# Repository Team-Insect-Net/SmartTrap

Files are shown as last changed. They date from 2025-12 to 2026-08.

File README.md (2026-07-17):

# SmartTrap v2.0

**Low-Power IoT Moth Trap Counter for Fall Armyworm Monitoring**

An automated monitoring system that detects, counts, and photographs moth entries into pheromone bucket traps. Designed for sustainable Fall Armyworm (FAW) management in agricultural settings.





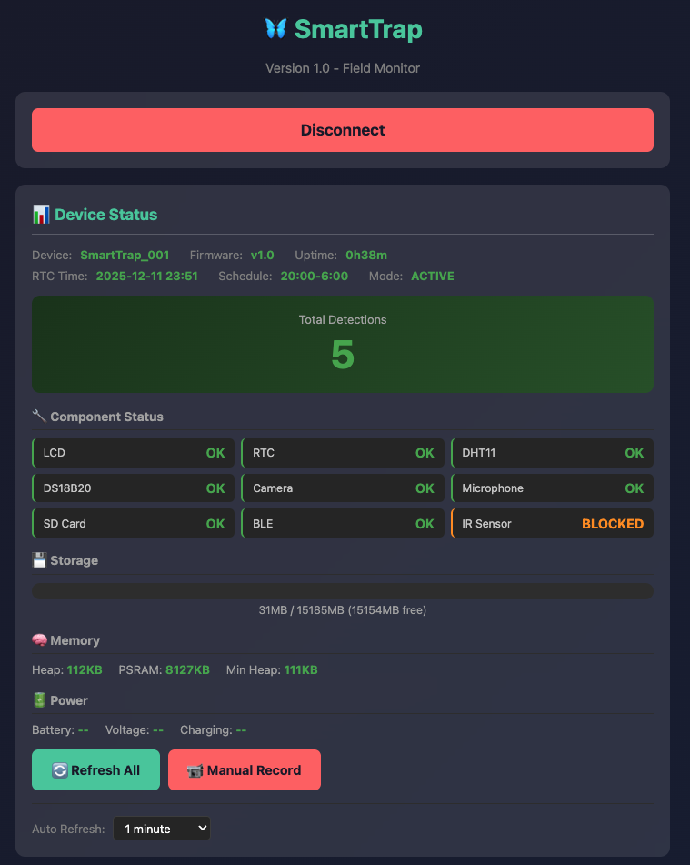
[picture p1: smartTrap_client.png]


---

## Overview

SmartTrap is a low-cost IoT device that automates the monitoring of Fall Armyworm moth populations. It uses a multi-beam infrared array to count moths entering pheromone traps, captures a JPEG image burst on each detection, and provides all control and data access over Bluetooth Low Energy (BLE) through the **SmartTrap Android app**.

> **v2.0 is a major redesign — BLE-native, button-less, and screen-less.** The phone app replaces the physical button and 16×2 LCD. The environmental sensors (air temperature/humidity, soil temperature, soil moisture) and AVI/WAV recording from v1.x have been removed; detections are now recorded as JPEG bursts. See the [changelog](#whats-new-in-v20).

### 📱 Android App

The SmartTrap Android app is the primary interface for the trap (status, diagnostics, time-setting, file browsing/download, count reset, and WiFi/USB control).

**Download the APK:** <https://drive.google.com/file/d/1rnNRD0PhtQwLzY0d07APNC46B7DXw_hL/view?usp=sharing>

Install by enabling "Install unknown apps" for your browser or file manager, open the downloaded APK, then grant Bluetooth (and Location, if prompted) permissions. Pair with the trap using passkey **`123456`**.

### Key Applications
- Fall Armyworm population monitoring
- Agricultural research and pest management
- Integrated Pest Management (IPM) decision support
- Scalable deployment across multiple field sites

### What's new in v2.0
- **[REMOVED]** Physical button and 16×2 LCD — all interaction is over BLE via the phone app
- **[REMOVED]** Environmental sensors (DHT11, DS18B20, soil moisture) and environmental logging
- **[CHANGED]** Detection recording is now a 10-frame JPEG burst (was AVI video + WAV audio)
- **[CHANGED]** IR detection upgraded to a 4-beam array driven from two pins
- **[NEW]** BLE re-added on the low-RAM NimBLE stack so it can coexist with the camera
- **[NEW]** On-demand WiFi SoftAP + HTTP server for fast bulk image download
- **[NEW]** Set the RTC from the phone app (`SETTIME`) — no re-flash or SetRTC sketch needed for routine time-setting

---

## Features

### Core Functionality
- **4-Beam IR Detection** - Multi-beam beam-break array with debounce filtering
- **JPEG Burst Capture** - 10-frame image burst (1s apart) on each detection
- **Scheduled Daily Photo** - Optional timed reference photo (default 08:00)
- **CSV Logging** - Detection events, beam-health, and daily-photo logs
- **SD Card Storage** - Local data storage with organized folder structure

### Data Management
- **Phone App over BLE** - Status, diagnostics, file browsing/download, and count reset from the Android app
- **On-Demand WiFi Download** - `WIFI:ON` raises a SoftAP + HTTP server for fast bulk image transfer
- **USB Mass Storage** - Mount the SD card as a USB drive via the `USB` BLE command
- **Auto Count Recovery** - Detection count derived from SD card data; survives reboots, resets on data deletion
- **Bonded BLE Security** - Passkey pairing with an encrypted link (legacy plaintext fallback for the old web client)

### Power Management
- **Scheduled Sleep Mode** - Optional configurable active hours (default off; 8 PM - 6 AM when enabled)
- **Deep Sleep** - Ultra-low power consumption during inactive periods
- **RTC-Timer Wake** - Wake from deep sleep on the DS3231 timer
- **Battery Support** - 3.7V LiPo battery or Power Bank (20,000 mAh) with USB charging

### Phone App (BLE)
- **Real-time Status** - Device info, uptime, schedule, detection count (`STATUS`)
- **Component Health** - Camera, mic, SD, RTC, BLE, and IR status (`DIAG`)
- **Memory Info** - Heap and PSRAM monitoring
- **Live Pushes** - `EVENT` on each detection, `BEAM:BLOCKED`/`BEAM:RESTORED` on beam-health changes
- **Time Sync** - Set the RTC from the app (`SETTIME`)

---

## Hardware Requirements

### Main Components

| Component | Model | Qty | Purpose |
|---|---|-----|---|
| Microcontroller | XIAO ESP32S3 Sense | 1 | Processing, camera, microphone, SD card |
| Real-Time Clock | DS3231 | 1 | Accurate timestamps |
| IR Emitter | 940nm LED | 4 | Beam-break transmitters |
| IR Receiver | 38kHz module | 4 | Beam-break receivers |
| Android phone | Runs the SmartTrap app (BLE 4.2+) | 1 | Device interface |

*Removed in v2.0: 16×2 LCD, DHT11, DS18B20, soil-moisture sensor, and push button.*



### Resistors Required (4 total)

| Value | Color Code | Purpose | Connection |
|---|---|---|---|
| 100Ω | Brown-Black-Brown | IR LED current limit (one per LED) | Drive pin → IR LED → GND |

*The IR receivers use the ESP32's internal pull-up (`INPUT_PULLUP`) — no external pull-up/pull-down resistors are needed.*

### Pin Configuration

```
D0 (GPIO1)  → IR LED pair #2 (LEDs #3+#4) via 100Ω each, 38kHz PWM
D1 (GPIO2)  → FREE (was DS18B20)
D2 (GPIO3)  → FREE (was DHT11)
D3 (GPIO4)  → FREE (was Button)
D4 (GPIO5)  → I2C SDA (RTC only)
D5 (GPIO6)  → I2C SCL (RTC only)
D6 (GPIO43) → IR LED pair #1 (LEDs #1+#2) via 100Ω each, 38kHz PWM
D7 (GPIO44) → IR Receivers ×4 (parallel, internal pull-up; blocked = LOW)
D8-D10      → RESERVED (SD Card - do not use)
```

---

## Software Requirements

### Arduino IDE Setup

1. **Install Arduino IDE 2.0+** from [arduino.cc](https://www.arduino.cc/en/software)

2. **Add ESP32 Board Package**
   - Go to `File → Preferences`
   - Add to "Additional Boards Manager URLs":
     ```
     https://raw.githubusercontent.com/espressif/arduino-esp32/gh-pages/package_esp32_index.json
     ```
   - Go to `Tools → Board → Boards Manager`
   - Search "esp32" and install (version 2.0.8 or higher)

3. **Select Board Settings**
   - Board: `ESP32S3 Dev Module`
   - USB CDC On Boot: `Enabled` ⚠️ Required for Serial output
   - PSRAM: `OPI PSRAM`
   - Port: Select your device port

### Required Libraries

Install via `Sketch → Include Library → Manage Libraries`:

- `NimBLE-Arduino` by h2zero (v1.4.x) - BLE stack (do **not** also enable Bluedroid)
- `RTClib` - DS3231 real-time clock

*The v1.x sensor/LCD libraries (LiquidCrystal I2C, DHT sensor library, OneWire, DallasTemperature) are no longer needed.*

---

## Installation

1. **Clone the repository**
   ```bash
   git clone https://github.com/Team-Insect-Net/SmartTrap.git
   cd SmartTrap
   ```

2. **Open the firmware**
   - Open `SmartTrap.ino` in Arduino IDE

3. **Configure settings** (optional)
   ```cpp
   #define DEVICE_NAME         "SmartTrap_001"    // Unique device ID (BLE + WiFi)
   #define BLE_PASSKEY         123456             // 6-digit BLE pairing passkey
   #define AUTH_PASSWORD       "smart2025"        // Legacy plaintext fallback
   #define WIFI_AP_PASSWORD    "trap12345"        // On-demand WiFi image server
   #define JPEG_BURST_COUNT    10                 // Frames captured per detection
   #define DAILY_PHOTO_HOUR    8                  // Scheduled daily photo (−1 = off)
   ```

4. **Upload to device**
   - Connect XIAO ESP32S3 Sense via USB-C
   - Select correct port in Arduino IDE
   - Click Upload

5. **Verify installation**
   - Open Serial Monitor (115200 baud)
   - Check all components show "OK"

---

## Usage

The device runs automatically on power-up — there is no button or LCD. Everything else is done from the **SmartTrap Android app** over BLE. Pair once with passkey **`123456`**; the bonded, encrypted link then authorizes protected commands.

### Connecting

1. Install and open the Android app (see [Android App](#-android-app) above)
2. Scan and connect to your trap (default BLE name `SmartTrap_001`)
3. Enter the pairing passkey `123456` when prompted

### BLE Commands

| Command | Access | Description |
|---|---|---|
| `STATUS` | open | Device info, uptime, schedule, detection count |
| `DIAG` | open | Camera/mic/SD/RTC/BLE/IR status + memory |
| `DETECTIONS` | open | Current detection count |
| `PING` | open | Liveness check (`PONG`) |
| `LIST` / `CD:` / `GET:` | protected | Browse and download SD card files |
| `DELETE:` / `RESET` | protected | Delete files / wipe data and zero the count |
| `SETTIME:YYYY-MM-DD HH:MM:SS` | protected | Set the RTC from the phone |
| `WIFI:ON` / `WIFI:OFF` | protected | Raise / tear down the WiFi image server |
| `USB` | protected | Mount the SD card as a USB Mass Storage drive |

Live pushes: `EVENT:det=…` on each detection, `BEAM:BLOCKED`/`BEAM:RESTORED` on beam-health changes. Full spec: **[BLE Protocol](docs/SmartTrap_v2.0_BLE_Protocol.md)**.

### Getting Data Off the Trap

- **Photos (fast):** send `WIFI:ON` → join the trap's WiFi (`SmartTrap_001` / `trap12345`) → download JPEGs over HTTP → `WIFI:OFF`
- **Logs:** browse with `LIST`/`CD` and download with `GET` over BLE
- **Bulk:** send `USB` to mount the SD card over USB-C, or pull the microSD card

### Resetting Detection Count

The moth count is derived from `detections.csv`. To reset: send **`RESET`** over BLE, or delete `/events/` and `/logs/` in USB drive mode, then reboot — count starts at 0.

### Legacy Web Client (optional)

The old `SmartTrap_v1.0_Client.html` still connects via the plaintext `AUTH:smart2025` fallback (Chrome + Web Bluetooth, served over localhost), but the Android app is the recommended interface.

### Data Files

```
/events/
  └── YYYYMMDD/                     # Daily detection folders
      └── img_<timestamp>_f<n>.jpg  # 10-frame JPEG burst per detection

/daily/
  └── YYYYMMDD_HH.jpg               # Scheduled daily photo(s)

/logs/
  ├── detections.csv               # Detection events
  ├── beam_health.csv              # IR beam block/restore log
  └── daily_photos.csv             # Scheduled-photo log
```

---

## Data Format

### detections.csv
```csv
timestamp,detection_num,event_dir,burst_timestamp,frames,audio_file
2026-07-17 21:45:32,1,/events/20260717,214532,10,
```

### beam_health.csv
```csv
timestamp,event,ir_receiver_state
2026-07-17 21:44:10,BLOCKED,LOW
```

*v2.0 records images and counts only — there is no environmental (`environment.csv`) logging.*

---

## Power Consumption

| Mode | Current | Duration (3000mAh) |
|---|---|---|
| Active monitoring | ~100-120mA | ~25-30 hours |
| Recording | ~300mA | - |
| Deep sleep | ~14µA | ~24 years |

### Estimated Battery Life

| Battery | Estimated Runtime |
|---|---|
| 3,000mAh | 7-10 days |
| 10,000mAh | 3-4 weeks |
| 20,000mAh | 6-8 weeks |

---

## Documentation

| Document | Description |
|---|---|
| [Hardware Guide](docs/SmartTrap_v2.0_Hardware_Guide.md) | Wiring diagrams, component list, assembly |
| [Firmware Guide](docs/SmartTrap_v2.0_Firmware_Guide.md) | Arduino setup, configuration, BLE commands |
| [Field Guide](docs/SmartTrap_v2.0_Field_Guide.md) | Deployment, maintenance, app-based data collection |
| [Quick Reference](docs/SmartTrap_v2.0_Quick_Reference.md) | Single-page printable card |
| [BLE Protocol](docs/SmartTrap_v2.0_BLE_Protocol.md) | GATT layout, pairing, command set, WiFi download |

*Legacy v1.0 guides remain in `docs/` for the pre-2.0 hardware.*

---

## Troubleshooting

| Problem | Solution |
|---|---|
| No Serial output | Enable "USB CDC On Boot" in Arduino IDE |
| Upload fails | Hold BOOT → Press RESET → Release → Upload |
| Compile error on `NimBLEDevice.h` | Install NimBLE-Arduino (h2zero, v1.4.x) |
| SD card not detected | Use FAT32 format, ≤32GB card |
| Phone won't pair | Confirm passkey `123456`; remove the old bond and re-pair |
| Protected command rejected | `ERROR:AuthRequired` — pair (bond) or send `AUTH:` first |
| False / missed detections | Re-align IR beams; check `DIAG` shows `ir=CLEAR` |
| RTC time wrong | Send `SETTIME:` from the app; check the DS3231 coin cell |
| WiFi download won't start | Send `WIFI:ON`; join `SmartTrap_001` / `trap12345` |
| Need USB drive mode | Send the `USB` command from the app |

---

## Contributing

Contributions are welcome! Please feel free to submit a Pull Request.

1. Fork the repository
2. Create your feature branch (`git checkout -b feature/AmazingFeature`)
3. Commit your changes (`git commit -m 'Add some AmazingFeature'`)
4. Push to the branch (`git push origin feature/AmazingFeature`)
5. Open a Pull Request

---

## License

This project is licensed under **Creative Commons Attribution-NonCommercial-ShareAlike 4.0 International (CC BY-NC-SA 4.0)**.

**You can:**
- Use for research and education
- Modify and build upon
- Share with others

**You must:**
- Give attribution (credit the original authors)
- Share modifications under the same license

**You cannot:**
- Use commercially without permission
- Remove attribution

See the [LICENSE](LICENSE) file for details. For commercial licensing, contact Penn State University.

---

## Acknowledgments

- **Penn State University** - Huck Institutes of the Life Sciences
- **CSIR-CRI Ghana** - Crops Research Institute
- **Seeed Studio** - XIAO ESP32S3 platform documentation
- **NSF INSECT NET** - Graduate training program inspiration

---

## Contact

**Project Lead:** Dr. Edward Idun Amoah  
**Institution:** Penn State University  
**Collaboration:** CSIR-CRI Ghana

---

<p align="center">
  <i>Part of the AI-Powered Monitoring and Modeling for Sustainable Fall Armyworm Management project</i>
</p>

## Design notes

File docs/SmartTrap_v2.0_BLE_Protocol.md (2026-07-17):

# SmartTrap v2.0 — BLE Protocol Specification

This document specifies the Bluetooth Low Energy (BLE) protocol used by SmartTrap
firmware v2.0 and the SmartTrap Android app. **Keep this file in sync with
`SmartTrap.ino`** — the firmware header points here as the source of truth.

In v2.0 the phone app is the primary human interface: it replaces the physical
button and the 16×2 LCD that existed in v1.x. All device interaction — status,
diagnostics, time-setting, file browsing/download, count reset, USB and WiFi
control — happens over this BLE link.

The stack is **NimBLE-Arduino** (h2zero, v1.4.x), chosen because it uses far less
RAM than Bluedroid and can therefore coexist with the camera. Do **not** also
enable the classic Bluedroid BLE.

---

## 1. GATT Layout

| Item | UUID | Direction | Properties |
|---|---|---|---|
| Service | `4fafc201-1fb5-459e-8fcc-c5c9c331914b` | — | — |
| Notify characteristic | `beb5483e-36e1-4688-b7f5-ea07361b26a8` | device → phone | Notify |
| Command characteristic | `beb5483e-36e1-4688-b7f5-ea07361b26a9` | phone → device | Write |

- The phone **subscribes** to the Notify characteristic to receive responses and
  live pushes.
- The phone **writes** UTF-8 command strings to the Command characteristic.
- The advertised device name is `DEVICE_NAME` (default `SmartTrap_001`).

---

## 2. Security & Pairing

v2.0 uses **bonded, passkey-protected, encrypted** connections.

- Security mode: bonding + MITM + LE Secure Connections
  (`NimBLEDevice::setSecurityAuth(true, true, true)`).
- Static passkey: **`123456`** (`BLE_PASSKEY`). The trap displays/holds the
  passkey; the phone enters it once, then bonds.
- After bonding, the link is **encrypted** and all protected commands are allowed.

### Legacy plaintext fallback

For the old v1.x Web Bluetooth client, an unencrypted fallback remains:

```
AUTH:<password>      → AUTH:OK | AUTH:FAIL   (default password: smart2025)
LOGOUT               → LOGOUT:OK
```

A command is authorized if the link is **either** bonded/encrypted **or** the
session has passed legacy `AUTH:`. Protected commands sent without either return
`ERROR:AuthRequired`.

> Security note: the legacy `AUTH:` path sends the password in clear text. Prefer
> bonded pairing (the Android app path). The plaintext password exists only for
> backward compatibility with the old browser client.

---

## 3. Command Set

### 3.1 Open commands (no auth required)

| Command | Response |
|---|---|
| `STATUS` | `STATUS:name=…,v=…,uptime=…,time=…,sched=…,active=YES/NO,det=…` |
| `DIAG` | `DIAG:…` then `MEMORY:…` (see §4) |
| `DETECTIONS` | `DETECTIONS:<count>` |
| `PING` | `PONG` |

### 3.2 Protected commands (bonded link or legacy `AUTH:`)

| Command | Description | Response |
|---|---|---|
| `LIST` or `LIST:/path` | List a directory (defaults to current dir) | `PATH:…`, `DIR:…`, `FILE:name:size` …, `LIST_END` |
| `CD:/path` | Change current directory | `PATH:<newdir>` |
| `GET:/path/file` | Stream a file in chunks | `FILE_START:path:size`, chunks, `FILE_END` |
| `GETCANCEL` | Abort an in-progress `GET` | `CANCELLED` |
| `DELETE:/path` | Delete a file or folder | `OK:…` / `ERROR:…` |
| `RESET` | Wipe `/events` + `/logs`, count → 0 | `OK:…` |
| `SETTIME:YYYY-MM-DD HH:MM:SS` | Set the DS3231 RTC from the phone | `OK:…` |
| `WIFI:ON` | Raise on-demand WiFi image server (§5) | `WIFI:…,IP=…,URL=…` |
| `WIFI:OFF` | Tear down the WiFi server | `OK:…` |
| `USB` | Mount the SD card as USB Mass Storage | `OK:USB` / `ERROR:NoSD` |

Unknown commands return `ERROR:UnknownCommand`.

---

## 4. Device → Phone Messages

### Live pushes (unsolicited)

| Message | When | Format |
|---|---|---|
| `EVENT:…` | On each moth detection | `EVENT:det=<count>,time=<ts>,frames=<n>,dir=/events/YYYYMMDD` |
| `BEAM:BLOCKED` | IR beam blocked beyond warning threshold | — |
| `BEAM:RESTORED` | IR beam clears again | — |

### Structured responses

```
STATUS:name=SmartTrap_001,v=2.0,uptime=3h12m,time=2026-07-17 21:05:00,sched=20:00-06:00,active=NO,det=42
DIAG:cam=OK,mic=OK,sd=OK,rtc=OK,ble=OK,ir=CLEAR
MEMORY:heap=180KB,psram=7200KB,minHeap=140KB
```

- `ir` is `CLEAR` or `BLOCKED`.
- File listing uses `DIR:<name>` for folders and `FILE:<name>:<bytes>` for files,
  terminated by `LIST_END`.
- File transfer: `FILE_START:<path>:<size>` → binary/base64 chunks on the Notify
  characteristic → `FILE_END` (or `CANCELLED` if aborted).

---

## 5. On-Demand WiFi Image Download

Transferring a 10-frame JPEG burst over BLE is slow, so v2.0 adds an **on-demand**
WiFi SoftAP + HTTP server for fast bulk image pulls. It is **off by default** to
save power and is raised only when the app sends `WIFI:ON`.

| Item | Value |
|---|---|
| SoftAP SSID | `DEVICE_NAME` (default `SmartTrap_001`) |
| SoftAP password | `trap12345` (`WIFI_AP_PASSWORD`, WPA2, ≥8 chars) |
| HTTP server port | `80` |

### HTTP endpoints

| Endpoint | Purpose |
|---|---|
| `GET /api/list` | JSON directory listing |
| `GET /api/events` | JSON list of detection-event folders/images |
| `GET /file?path=/events/…/img_….jpg` | Download a single file |

Workflow: `WIFI:ON` over BLE → app joins the SoftAP → app pulls JPEGs over HTTP →
`WIFI:OFF` to power the radio back down.

---

## 6. On-Disk Layout (referenced by the protocol)

```
/events/YYYYMMDD/img_<timestamp>_f<n>.jpg   # 10-frame JPEG burst per detection
/daily/YYYYMMDD_HH.jpg                       # scheduled daily photo(s)
/logs/detections.csv                         # timestamp,detection_num,event_dir,burst_timestamp,frames,audio_file
/logs/beam_health.csv                        # timestamp,event,ir_receiver_state
/logs/daily_photos.csv                       # scheduled-photo log
```

The detection count is **derived from `detections.csv`** on boot, so it survives
reboots and resets to 0 when the logs are cleared (`RESET`, or deleting the folders
in USB drive mode).

---

*SmartTrap v2.0 — Penn State University & CSIR-CRI Ghana. Licensed CC BY-NC-SA 4.0.*

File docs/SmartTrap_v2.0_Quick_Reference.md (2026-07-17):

# SmartTrap v2.0 — Quick Reference

**Android app (APK):**
<https://drive.google.com/file/d/1rnNRD0PhtQwLzY0d07APNC46B7DXw_hL/view?usp=sharing>

v2.0 has **no button and no LCD** — the phone app is the interface.

## Pin Connections

```
D0 (GPIO1)  → IR LED pair #2 (LEDs #3+#4) via 100Ω each, 38kHz PWM
D1 (GPIO2)  → FREE (was DS18B20)
D2 (GPIO3)  → FREE (was DHT11)
D3 (GPIO4)  → FREE (was Button)
D4 (GPIO5)  → I2C SDA (RTC only)
D5 (GPIO6)  → I2C SCL (RTC only)
D6 (GPIO43) → IR LED pair #1 (LEDs #1+#2) via 100Ω each, 38kHz PWM
D7 (GPIO44) → IR Receivers ×4 (parallel, internal pull-up; blocked = LOW)
D8-D10      → RESERVED (SD Card)
```

## App / BLE Pairing

| Item | Value |
| --- | --- |
| BLE name | SmartTrap_001 |
| Pairing passkey | 123456 |
| Legacy password | smart2025 (old web client only) |
| WiFi SSID / pass | SmartTrap_001 / trap12345 |

## Default Settings

| Setting | Value |
| --- | --- |
| Detection recording | 10-frame JPEG burst (1s apart) |
| Post-detection cooldown | 60 s |
| Daily photo | 08:00 (second photo off) |
| Scheduled sleep | Off by default (active 8 PM–6 AM if enabled) |
| IR carrier | 38 kHz PWM |

## BLE Commands

**Open:** `STATUS` · `DIAG` · `DETECTIONS` · `PING`

**Protected (pair first, or `AUTH:smart2025`):**
`LIST` · `CD:/path` · `GET:/path/file` · `DELETE:/path` · `RESET` ·
`SETTIME:YYYY-MM-DD HH:MM:SS` · `WIFI:ON` · `WIFI:OFF` · `USB`

**Live pushes:** `EVENT:det=…` (each detection) · `BEAM:BLOCKED` / `BEAM:RESTORED`

## Files on SD

| Path | Description |
| --- | --- |
| /events/YYYYMMDD/img_*.jpg | Detection JPEG bursts |
| /daily/YYYYMMDD_HH.jpg | Scheduled daily photos |
| /logs/detections.csv | Detection events |
| /logs/beam_health.csv | Beam block/restore log |
| /logs/daily_photos.csv | Daily-photo log |

*No environmental logging in v2.0 (DHT11 / DS18B20 / soil-moisture removed).*

## Get Data Off the Trap

- **Photos fast:** `WIFI:ON` → join `SmartTrap_001` WiFi → download → `WIFI:OFF`
- **Logs:** `LIST` / `GET` over BLE
- **Bulk:** `USB` command → copy over USB-C, or pull the SD card

## Reset Detection Count

Send `RESET` over BLE, or delete `/events` + `/logs` in USB drive mode and reboot.
Count is derived from `detections.csv` — no data = count starts at 0.

## Set the Clock

Send `SETTIME:YYYY-MM-DD HH:MM:SS` from the app (no re-flash needed).

## Quick Fixes

| Problem | Fix |
| --- | --- |
| No serial | Enable USB CDC On Boot |
| Upload fail | BOOT → RESET → Release |
| `NimBLEDevice.h` error | Install NimBLE-Arduino (h2zero, v1.4.x) |
| SD error | FAT32, ≤32GB |
| Can't pair | Passkey 123456; remove old bond, re-pair |
| Wrong time | Send `SETTIME:` from app |

---

*Penn State & CSIR-CRI Collaboration — SmartTrap v2.0*

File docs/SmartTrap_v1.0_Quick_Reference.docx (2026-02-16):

# SmartTrap v1.0 - Quick Reference

## Pin Connections

D0 (GPIO1) → Soil Moisture AO

D1 (GPIO2) → DS18B20 DATA + 4.7kΩ pull-up to 3.3V

D2 (GPIO3) → DHT11 DATA

D3 (GPIO4) → Button → GND + 10kΩ pull-up to 3.3V

D4 (GPIO5) → I2C SDA (LCD + RTC)

D5 (GPIO6) → I2C SCL (LCD + RTC)

D6 (GPIO43) → IR LED (+) via 100Ω

D7 (GPIO44) → IR Receiver OUT + 10kΩ pull-down to GND

D8-D10 → RESERVED (SD Card)

## Button Controls

During startup countdown: Press BTN → USB Drive Mode

Short press (<1s): Toggle LCD backlight

Long press (5s): Toggle BLE on/off

Press during sleep: Wake device

## Default Settings

Password: smart2025

Active hours: 8 PM - 6 AM

Recording: 10s @ 15 FPS

Env logging: Every 1 minute

BLE Name: SmartTrap_001

## Log Files

/logs/environment.csv - Periodic env data

/logs/detections.csv - Moth events + env

/events/YYYYMMDD/ - Video/audio files

## Startup Modes

Normal Mode (default): Don't press button → Monitoring starts

USB Drive Mode: Press BTN during countdown → Data transfer

BLE Data Transfer: Use web client, authenticate, download files

## Env Logging Intervals

60000 = 1 min | 300000 = 5 min | 3600000 = 1 hour

## BLE Commands (Public)

STATUS - Device info, time, schedule, detections

DIAG - Component status, memory, storage, battery

SENSORS - Environmental sensor readings

DETECTIONS - Current detection count

RECORD - Trigger manual recording

## BLE Commands (Protected)

AUTH:password - Authenticate for data access

LIST:/path - List directory contents

GET:/path/file - Download file

DELETE:/path/file - Delete file

RESET - Factory reset (deletes all data)

## Quick Fixes

No serial: Enable USB CDC On Boot

Upload fail: BOOT → RESET → Release

SD error: FAT32, ≤32GB

Penn State & CSIR-CRI Collaboration

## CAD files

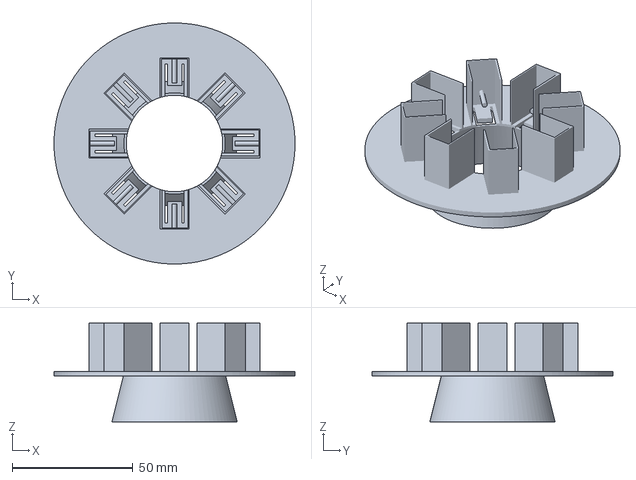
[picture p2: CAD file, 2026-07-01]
stl_files/disk.3mf
100.0 x 100.0 x 41.0 mm

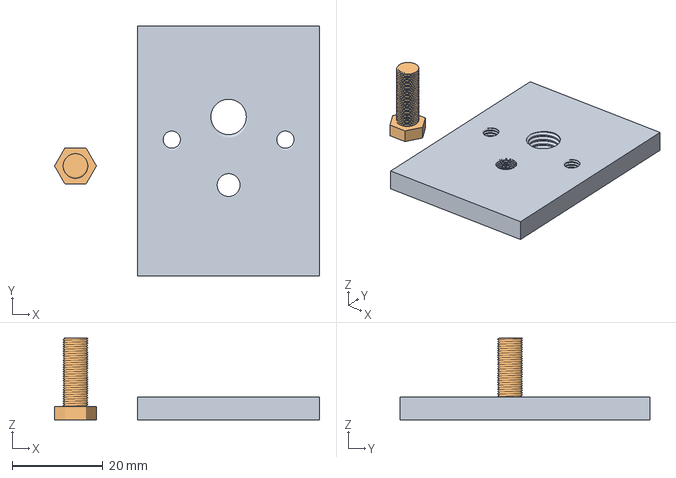
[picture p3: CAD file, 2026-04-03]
stl_files/funnel_connector.3mf
58.3 x 55.0 x 18.0 mm
connector_plate.stl
large_bolt.stl

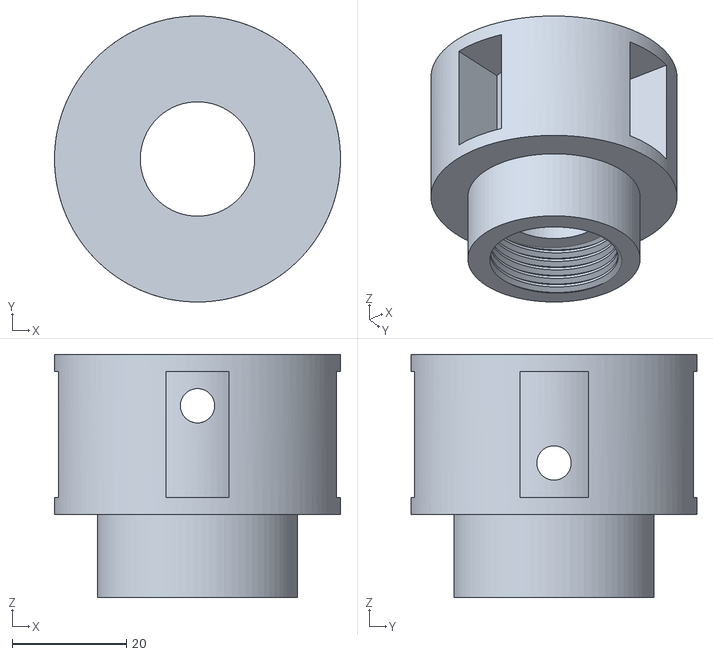
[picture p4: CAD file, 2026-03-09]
stl_files/Sensor_connector.stl
50.0 x 50.0 x 42.6

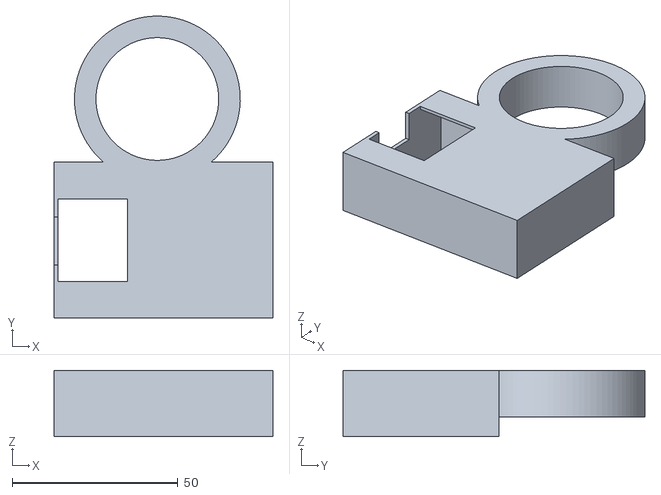
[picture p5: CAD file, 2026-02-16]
stl_files/mcu_connector.stl
66.0 x 91.0 x 20.0

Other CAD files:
stl_files/disk.stl
stl_files/funnel_connector.stl

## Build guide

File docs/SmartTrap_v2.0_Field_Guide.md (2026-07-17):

# SmartTrap v2.0 — Field Deployment & Maintenance Guide

In v2.0 all field interaction is through the **SmartTrap Android app** over
Bluetooth — there is no button or LCD on the device.

**Android app (APK):**
<https://drive.google.com/file/d/1rnNRD0PhtQwLzY0d07APNC46B7DXw_hL/view?usp=sharing>

> Install by enabling "Install unknown apps" for your browser/file manager, then
> open the downloaded APK. Grant Bluetooth (and Location, if prompted) permissions.

---

## 1. Field Deployment

### Site Selection

- Place the trap at the field edge or within the crop canopy
- Avoid direct sunlight on the electronics
- Ensure each IR beam path is clear across the trap throat
- Keep the phone within BLE range (~10m) when checking on the trap

### Installation Checklist

- [ ] SD card formatted FAT32 (≤32GB)
- [ ] Power bank fully charged
- [ ] Phone paired with the trap (passkey **123456**)
- [ ] RTC time set from the app (`SETTIME`)
- [ ] Fresh pheromone lure
- [ ] All 4 IR beams aligned (`DIAG` shows `ir=CLEAR`)
- [ ] Enclosure sealed

### Expected Battery Life

| Power Bank | Capacity | Runtime |
| --- | --- | --- |
| Small | 10,000 mAh | 3–4 weeks |
| Medium | 20,000 mAh | 6–8 weeks |

---

## 2. Maintenance Schedule

### Weekly

- Check power bank level (app `STATUS` → uptime)
- Clear the trap of accumulated insects
- Verify IR beams with `DIAG` (`ir=CLEAR`) or watch for `BEAM:BLOCKED` pushes

### Bi-Weekly

- Replace pheromone lure (2–4 weeks)
- Clean the camera lens
- Inspect for moisture

### Monthly

- Full image + log export (WiFi image download, or USB drive mode)
- `RESET` from the app to clear data and zero the count (optional)
- Confirm RTC time; re-send `SETTIME` if it has drifted

---

## 3. Data Collection

### Files on the SD card

| Path | Contents |
| --- | --- |
| /events/YYYYMMDD/img_*.jpg | 10-frame JPEG burst per detection |
| /daily/YYYYMMDD_HH.jpg | Scheduled daily photo(s) |
| /logs/detections.csv | Detection events: timestamp, count, event dir, frames |
| /logs/beam_health.csv | IR beam block/restore events |
| /logs/daily_photos.csv | Scheduled-photo log |

> v2.0 records images and counts only — there is **no environmental (temperature/
> humidity/soil) logging**.

### Method A — Fast image download over WiFi (recommended for photos)

1. In the app, send **`WIFI:ON`** — the trap starts a WiFi hotspot
   (SSID `SmartTrap_001`, password `trap12345`) and reports its URL.
2. Join that WiFi from the phone and download the JPEGs over HTTP.
3. Send **`WIFI:OFF`** when done to save power.

### Method B — File browse/download over BLE (good for logs)

1. Connect and pair in the app.
2. Browse with `LIST` / `CD`, then `GET` the CSV logs or individual images.

### Method C — USB drive mode (bulk offload at a bench)

1. In the app, send **`USB`** — the SD card mounts as a USB Mass Storage drive.
2. Plug the trap into a computer with USB-C and copy `/events`, `/daily`, `/logs`.
3. Safely eject and unplug.

### Method D — SD card reader (fastest bulk transfer)

1. Power off the trap, remove the microSD card.
2. Copy the folders using a USB card reader, then re-insert and power on.

### Resetting the detection count

The count is derived from `detections.csv`. To reset: send **`RESET`** over BLE
(wipes `/events` + `/logs`, count → 0), or delete those folders in USB drive mode
and reboot.

---

## 4. Common Field Issues

| Issue | Solution |
| --- | --- |
| False detections | Re-align IR beams; shield from wind and stray IR/sunlight |
| Missed detections | Clean IR emitters/receivers; confirm `ir=CLEAR` in `DIAG` |
| `BEAM:BLOCKED` alerts | Clear debris from the beam path; re-align LED/receiver |
| Can't connect | Re-pair (passkey 123456); confirm the trap has power |
| Moisture damage | Improve sealing, add desiccant |
| SD card full | Download data, then `RESET` or delete folders |

---

## 5. Support

**Project PI:** Dr. Edward Idun Amoah (Penn State)
**Ghana PI:** Dr. Kofi Frimpong-Anin (CSIR-CRI)

---

*SmartTrap v2.0 — Penn State & CSIR-CRI collaboration. Licensed CC BY-NC-SA 4.0.*

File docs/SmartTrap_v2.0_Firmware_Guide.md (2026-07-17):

# SmartTrap v2.0 — Firmware Installation & Configuration Guide

## 1. Prerequisites

### Required Software

- Arduino IDE 2.0+ (download from arduino.cc)
- ESP32 Board Package (version 2.0.8 or higher)
- **SmartTrap Android app** (the phone is the device interface in v2.0)

### Required Libraries

Install via the Arduino Library Manager:

- **NimBLE-Arduino** by h2zero (v1.4.x) — the BLE stack
- **RTClib** by Adafruit — DS3231 real-time clock

> Do **not** enable the classic Bluedroid BLE — NimBLE replaces it and uses far
> less RAM, which is what lets BLE coexist with the camera.
>
> The v1.x sensor libraries (LiquidCrystal_I2C, DHT sensor library, OneWire,
> DallasTemperature) are **no longer needed** — the LCD and environmental sensors
> were removed in v2.0.

---

## 2. Arduino IDE Setup

- Open **File → Preferences**
- Add to *Additional Boards Manager URLs*:
  `https://raw.githubusercontent.com/espressif/arduino-esp32/gh-pages/package_esp32_index.json`
- **Tools → Board → Boards Manager** → search "esp32" → install
  "esp32 by Espressif Systems"
- **Tools → Board → esp32** → select **ESP32S3 Dev Module**
- **CRITICAL:** set **USB CDC On Boot → Enabled**
- Set **PSRAM → OPI PSRAM**

### Port Selection

- Mac: `/dev/cu.usbmodem101` (or `/dev/cu.usbmodemXXXX`)
- Windows: COM3, COM4, or higher
- Linux: `/dev/ttyACM0` or `/dev/ttyUSB0`

**Tip:** Unplug the device, note the ports, plug it back in — the new port is your
XIAO.

---

## 3. Configuration Options

Edit these values near the top of `SmartTrap.ino`:

| Setting | Default | Description |
| --- | --- | --- |
| DEVICE_NAME | "SmartTrap_001" | BLE + WiFi SoftAP name |
| BLE_PASSKEY | 123456 | 6-digit BLE pairing passkey |
| REQUIRE_AUTH | true | Gate data commands behind an encrypted link |
| AUTH_PASSWORD | "smart2025" | Legacy plaintext fallback (old web client) |
| WIFI_AP_PASSWORD | "trap12345" | On-demand WiFi image-server password (WPA2) |
| ENABLE_WIFI | true | Allow the on-demand WiFi image server |
| IR_PWM_FREQUENCY | 38000 | IR LED carrier frequency (matches receivers) |
| IR_DEBOUNCE_MS | 150 | Detection debounce |
| JPEG_BURST_COUNT | 10 | Frames captured per detection |
| JPEG_BURST_INTERVAL_MS | 1000 | Delay between burst frames |
| POST_DETECTION_COOLDOWN_MS | 60000 | Ignore new detections for 60s after one |
| DAILY_PHOTO_HOUR | 8 | Hour for the scheduled daily photo (−1 = off) |
| DAILY_PHOTO_HOUR_2 | −1 | Optional second daily photo (−1 = off) |
| ENABLE_SCHEDULED_SLEEP | false | Enable the active-hours sleep schedule |
| ACTIVE_START_HOUR | 20 (8 PM) | Hour to start monitoring |
| ACTIVE_END_HOUR | 6 (6 AM) | Hour to stop monitoring |
| USB_MSC_ENABLED | true | Allow the `USB` BLE command to mount the SD card |

---

## 4. Recording & Data Logging

On each IR detection the firmware captures a **10-frame JPEG burst** (no AVI video
or WAV audio — those were removed in v2.0) and writes it to the SD card.

### On-disk layout

```
/events/YYYYMMDD/img_<timestamp>_f<n>.jpg   # detection burst frames
/daily/YYYYMMDD_HH.jpg                       # scheduled daily photo(s)
/logs/detections.csv
/logs/beam_health.csv
/logs/daily_photos.csv
```

### detections.csv format

```
timestamp, detection_num, event_dir, burst_timestamp, frames, audio_file
```

### beam_health.csv format

```
timestamp, event, ir_receiver_state
```

> **No environmental logging.** v2.0 removed the DHT11 / DS18B20 / soil-moisture
> sensors, so there is no `environment.csv` and detection rows carry no temperature
> or humidity columns.

### Detection count recovery

The detection count is **derived from `detections.csv`** on boot, so it survives
reboots and returns to 0 when the logs are cleared (via the BLE `RESET` command or
by deleting the folders in USB drive mode).

---

## 5. Phone App Control (BLE)

All interaction happens over BLE — there is no button or LCD. Pair the phone once
(passkey **123456**); the bonded, encrypted link then authorizes protected
commands. See **[BLE Protocol](SmartTrap_v2.0_BLE_Protocol.md)** for the full spec.

### Open commands (no auth)

| Command | Description |
| --- | --- |
| STATUS | Name, firmware, uptime, time, schedule, active state, count |
| DIAG | Camera/mic/SD/RTC/BLE/IR status + heap/PSRAM memory |
| DETECTIONS | Current detection count |
| PING | Liveness check (returns `PONG`) |

### Protected commands (bonded link, or legacy `AUTH:password`)

| Command | Description |
| --- | --- |
| LIST / LIST:/path | Browse SD card directories |
| CD:/path | Change directory |
| GET:/path/file | Download a file over BLE |
| DELETE:/path | Delete a file or folder |
| RESET | Wipe `/events` + `/logs`, count → 0 |
| SETTIME:YYYY-MM-DD HH:MM:SS | Set the RTC from the phone |
| WIFI:ON / WIFI:OFF | Raise / tear down the WiFi image server |
| USB | Mount the SD card as a USB Mass Storage drive |

### Live pushes

- `EVENT:det=…,time=…,frames=…,dir=…` on every detection
- `BEAM:BLOCKED` / `BEAM:RESTORED` on beam-health changes

---

## 6. Fast Image Download over WiFi

A 10-frame JPEG burst is slow to pull over BLE, so v2.0 adds an **on-demand** WiFi
SoftAP + HTTP server (off by default to save power):

1. In the app, send **`WIFI:ON`** — the trap starts a SoftAP named `DEVICE_NAME`
   (default `SmartTrap_001`, password `trap12345`) and returns its IP/URL.
2. Join that WiFi network from the phone and pull images via HTTP
   (`/api/list`, `/api/events`, `/file?path=…`).
3. Send **`WIFI:OFF`** to power the radio back down.

---

## 7. RTC Clock

The DS3231 keeps time in the field on its coin cell (~1 min/year drift). In v2.0 you
set the clock **from the phone app**:

- Send **`SETTIME:YYYY-MM-DD HH:MM:SS`** over BLE — no re-flash and no separate
  SetRTC sketch needed for routine time-setting (the SetRTC sketch still works if
  you prefer it).
- On boot the firmware does **not** silently trust its own timestamps until you sync
  from the app.

---

## 8. Power Management

- **Scheduled sleep is OFF by default** (`ENABLE_SCHEDULED_SLEEP = false`). Set it
  `true` to sleep outside the `ACTIVE_START_HOUR`–`ACTIVE_END_HOUR` window.
- Deep-sleep wake is **RTC-timer only** in v2.0 (the button ext0 wake was removed
  with the button).
- USB Mass Storage is started on the BLE **`USB`** command, not a boot-time button
  press.

---

## 9. Troubleshooting

| Problem | Solution |
| --- | --- |
| No Serial output | Enable "USB CDC On Boot" in Tools |
| Upload fails | Hold BOOT, press RESET, release, upload |
| Compile error on `NimBLEDevice.h` | Install NimBLE-Arduino (h2zero, v1.4.x) |
| SD card not detected | FAT32 format, ≤32GB, firmly seated |
| Phone won't pair | Confirm passkey `123456`; remove old bond and re-pair |
| Protected command rejected | `ERROR:AuthRequired` — pair (bond) or send `AUTH:` first |
| RTC time wrong | Send `SETTIME:` from the app; check the coin cell |
| WiFi download won't start | Send `WIFI:ON`; SSID `SmartTrap_001`, pass `trap12345` |

---

*SmartTrap v2.0 — Penn State & CSIR-CRI collaboration. Licensed CC BY-NC-SA 4.0.*

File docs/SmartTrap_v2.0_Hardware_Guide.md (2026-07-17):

# SmartTrap v2.0 — Hardware Assembly Guide

## 1. System Overview

SmartTrap is an automated monitoring system that detects and counts Fall Armyworm
moths entering pheromone traps. It uses an infrared beam-break array, records a
JPEG image burst on each detection, and provides all data access and control over
Bluetooth Low Energy (BLE) through the **SmartTrap Android app**.

### What changed from v1.x

v2.0 is **button-less and screen-less** — the phone app is the human interface.

- **[REMOVED]** 16×2 I2C LCD (status now shown in the app)
- **[REMOVED]** Physical push button (all interaction is over BLE)
- **[REMOVED]** Environmental sensors — DHT11 (air temp/humidity), DS18B20 (soil
  temp), and the capacitive soil-moisture sensor are gone. v2.0 does **not** log
  environmental data.
- **[CHANGED]** Detection recording is now a **10-frame JPEG burst**, not AVI
  video + WAV audio.
- **[CHANGED]** IR detection is now a **4-beam array** driven from two pins.
- **[NEW]** BLE re-added via the low-RAM **NimBLE** stack, plus an on-demand WiFi
  image server for fast bulk photo download.

### Key Features

- Multi-beam IR beam-break moth detection (4 beams)
- 10-frame JPEG burst per detection (camera)
- Optional scheduled daily photo
- SD card storage (JPEG + CSV logs)
- BLE control, diagnostics, file browsing, and count reset from the phone app
- On-demand WiFi SoftAP for fast image download
- RTC-scheduled deep sleep for extended battery life

---

## 2. Required Components

| Component | Specification | Qty | Cost |
| --- | --- | --- | --- |
| Microcontroller | XIAO ESP32S3 Sense | 1 | $15 |
| Expansion Board | XIAO Sense Camera/Mic Board | 1 | $10 |
| Real-Time Clock | DS3231 RTC Module | 1 | $8 |
| IR LED | 940nm IR Emitter (5mm) | 4 | $4 |
| IR Receiver | 38kHz IR Receiver Module | 4 | $4 |
| SD Card | MicroSD FAT32 (≤32GB) | 1 | $8 |
| Resistors | 100Ω (one per IR LED) | 4 | $0.40 |
| Power Bank | USB 10,000–20,000mAh | 1 | $15–25 |
| Android phone | Runs the SmartTrap app (BLE 4.2+) | 1 | — |
| **TOTAL** | | | **~$65–75** |

> Removed vs v1.x: LCD, DHT11, DS18B20, soil-moisture sensor, push button, and
> their pull-up/pull-down resistors.

---

## 3. Pin Configuration (v2.0)

| XIAO Pin | GPIO | Connection | Notes |
| --- | --- | --- | --- |
| D0 | GPIO1 | IR LED pair #2 (LEDs #3+#4) | via 100Ω each, 38kHz PWM |
| D1 | GPIO2 | FREE | was DS18B20 |
| D2 | GPIO3 | FREE | was DHT11 |
| D3 | GPIO4 | FREE | was Button |
| D4 | GPIO5 | I2C SDA (RTC only) | LCD removed |
| D5 | GPIO6 | I2C SCL (RTC only) | LCD removed |
| D6 | GPIO43 | IR LED pair #1 (LEDs #1+#2) | via 100Ω each, 38kHz PWM |
| D7 | GPIO44 | IR Receivers ×4 (parallel OUT) | INPUT_PULLUP (internal); beam-broken = LOW |
| D8–D10 | GPIO7,8,9 | RESERVED — SD Card | DO NOT USE |

**IMPORTANT:** Pins D8, D9, D10 (GPIO 7, 8, 9) are used internally by the expansion
board's SD card slot.

---

## 4. Wiring Connections

### Power Distribution

- 3.3V → RTC, IR receiver modules
- 5V (or 3.3V per module rating) → IR receiver VCC if required
- GND → all component GND pins (common ground)

### IR Beam-Break Array (4 beams)

The four beams share two drive pins and one receiver pin:

- **LEDs #1 + #2:** anode (+) → 100Ω resistor → **D6 (GPIO43)**, cathode (−) → GND
- **LEDs #3 + #4:** anode (+) → 100Ω resistor → **D0 (GPIO1)**, cathode (−) → GND
  (each LED gets its own 100Ω resistor)
- **Receivers ×4:** VCC → 3.3V, GND → GND, all four **OUT tied together → D7
  (GPIO44)**
- D7 uses the ESP32's **internal pull-up** (`INPUT_PULLUP`) — no external resistor
  needed. A blocked beam pulls the line **LOW**.
- The LEDs are driven with a **38kHz PWM** carrier to match the receiver modules.
- Position each LED facing its receiver across the trap throat, 2–5cm apart.

### I2C Bus (RTC only)

- DS3231 SDA → D4 (GPIO5)
- DS3231 SCL → D5 (GPIO6)
- DS3231 VCC → 3.3V, GND → GND
- Keep the DS3231 coin cell installed so the clock survives power loss.

---

## 5. Verification Checklist

- [ ] SD card inserted and formatted FAT32 (≤32GB)
- [ ] Expansion board attached (audible click)
- [ ] No shorts between 3.3V and GND
- [ ] Each IR LED has its own 100Ω resistor (Brown-Black-Brown)
- [ ] All 4 IR receiver OUT lines tied to D7 (no external pull-up — internal used)
- [ ] DS3231 wired to D4/D5 with coin cell installed
- [ ] D8–D10 pins are NOT connected
- [ ] Each IR LED aligned with its receiver (2–5cm gap)
- [ ] No LCD, button, or environmental sensors wired (removed in v2.0)

**Tip:** Use a phone camera to verify each IR LED is emitting — it will appear as
a faint purple glow.

---

*SmartTrap v2.0 — Penn State & CSIR-CRI collaboration. Licensed CC BY-NC-SA 4.0.*

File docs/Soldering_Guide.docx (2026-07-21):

Soldering Guide

General Tips

1. Prep the Iron: Heat your iron to roughly 350 °C (650 °F - 750 °F). Make sure the tip of the iron is clean for optimal heat transfer. Wipe the tip on damp brass/sponge.
2. Apply heat: Touch the tip of the iron to both the component lead and the copper pad at the same time. Wait 2 to 3 seconds for the metal to heat up.
3. Feed Solder: Touch your solder wire to the heated joint (not the iron itself). Let the pad and lead melt the solder so it flows evenly.
4. Cool: Remove the solder and iron, then let the joint cool completely without moving the component.

Note: Heat the joint, not the solder. Don’t use too much solder, as it can cause short circuits and other issues.

SmartTrap Soldering

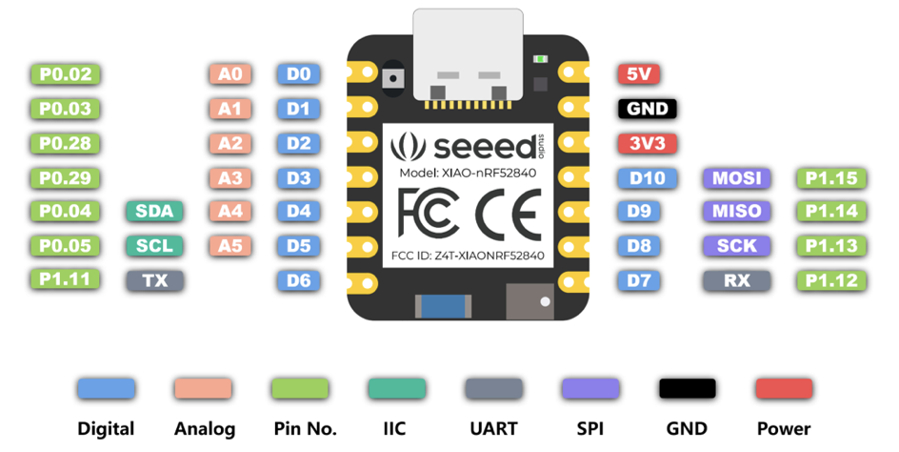
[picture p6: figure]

Figure 0. Seeed Studio pin layout.

1. Insert the seeed studio into the prototype board and solder the pins. Make sure to leave at least 2 pins on each side of the seeed microcontroller (Figure 1).

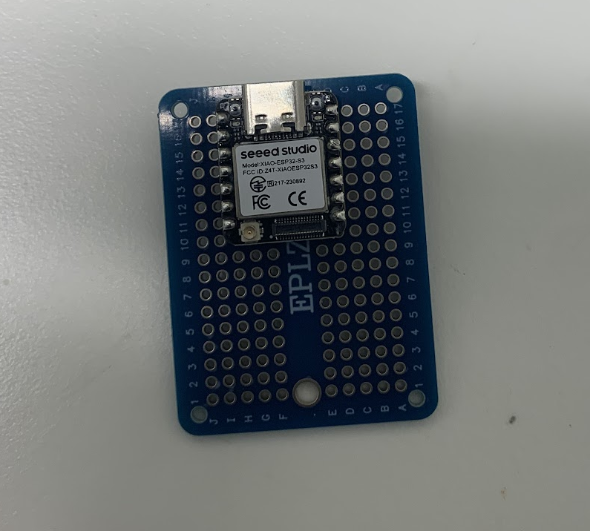
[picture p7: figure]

Figure 1. Seeed studio inserted into a prototype board

2. Insert wires to Jump the ground and 3V connections. You can bend the wires behind the board to secure the wires before soldering. Make sure to leave at least 2 or three lines between jump destinations (Figure 2). Extend the ground for three lines, and 2 lines for the 3V connection (Figure 2C).

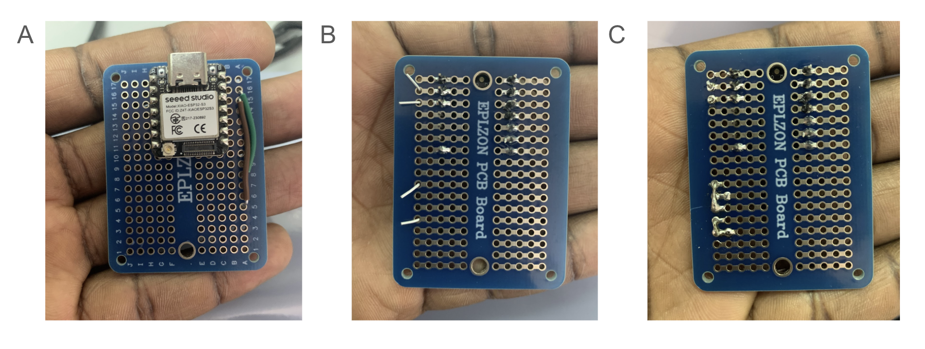
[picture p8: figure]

Figure 2. Solder power extensions for the board.

3. Solder Male header pins to the board. This will make it easy to connect the other components securely to the prototype board. Insert the header pins into the board (Figure 3A). You can use tape to keep the pins in place before soldering (Figure 3B). This will prevent the pins from falling off when you flip the board for soldering. You can also tape the board to the bench to secure it for soldering (Figure 3C).

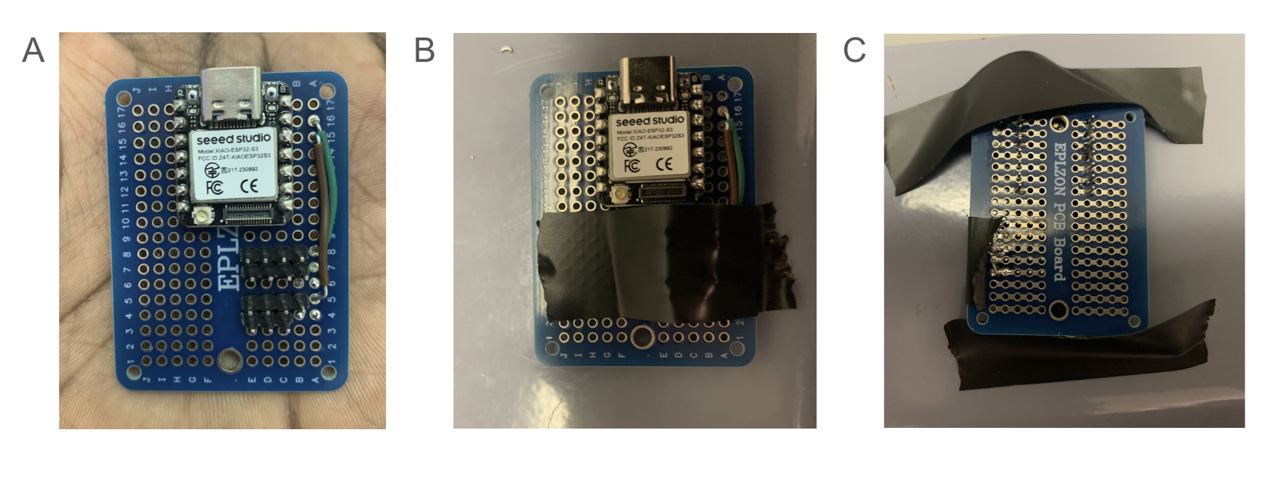
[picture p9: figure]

Figure 3. Solder Male header pins to the prototype. This will make it easy to connect components to the board securely.

4. Solder all other Male header pins for all connections to the board. Use the same procedure as in step 3. Insert the pins, tape the pins, flip the board, and solder. Do this until all header pins are soldered to the prototype board. The final board should have 2 pins for D0, D1, D4, D5, D6, and D7. D3 and 5V only need one pin. Finally, the ground should have 11 pins, and 3V should have 7 pins (Figure 4C).

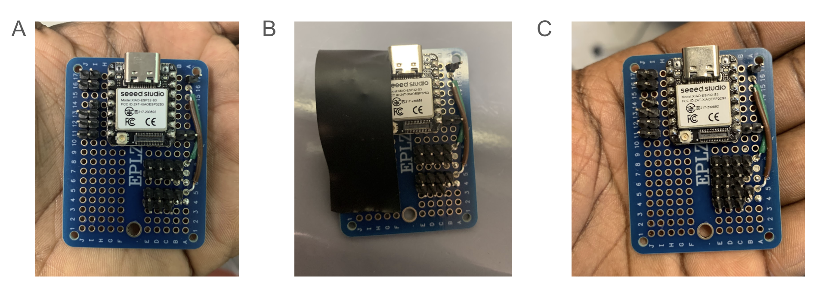
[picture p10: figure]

Figure 4. Solder all other connection pins to the board.

Additional Resources

1. https://www.ifixit.com/News/97850/soldering-simplified-a-newbies-guide-to-through-hole-soldering

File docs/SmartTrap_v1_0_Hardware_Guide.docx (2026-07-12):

# SmartTrap v1.0

Hardware Assembly Guide

# 1. System Overview

The SmartTrap is an automated monitoring system designed to detect and count Fall Armyworm moths entering pheromone traps. It uses dual-pair infrared beam-break detection (4 LEDs + 4 receivers on D6 and D0) in a star pattern for maximum sensitivity, records JPEG image evidence, and provides wireless data access via Bluetooth.

## Key Features

- Automatic moth detection via 4 IR beam-break sensors (2 pairs on D6 + D0, star pattern)
- 10-frame JPEG burst capture per detection event
- Environmental sensors removed in this build to free D0 for IR LED pair #2
- Detection logging with CSV format (environmental sensors not installed)
- SD card data logging with CSV format
- BLE removed in firmware v1.5 (frees memory for camera)
- Scheduled sleep mode for extended battery life
- Password protection for data security

# 2. Required Components

Component | Specification | Qty | Cost
Microcontroller | XIAO ESP32S3 Sense | 1 | $15
Expansion Board | XIAO Sense Camera/Mic Board | 1 | $10
LCD Display | 16x2 I2C LCD (0x27 or 0x3F) | 1 | $5
Real-Time Clock | DS3231 RTC Module | 1 | $8
IR LED | 940nm IR Emitter (5mm), 2 pairs | 4 | $1
IR Receiver | TSOP38238 IR Receiver (38kHz, 940nm) | 4 | $1
DHT11 (REMOVED) | Not installed — pin D2 free | 1 | $3
DS18B20 (REMOVED) | Not installed — pin D1 free | 1 | $5
Soil Moisture (REMOVED) | Not installed — pin D0 used for IR | 1 | $3
Push Button | 4-pin Tactile Switch | 1 | $1
SD Card | MicroSD FAT32 (≤32GB) | 1 | $8
Resistors | 2.2kΩ (x2 for I2C) | 1 each | $0.30
Power Bank | USB 10,000-20,000mAh | 1 | $15-25
TOTAL | | | ~$75-90

# 3. Pin Configuration

XIAO Pin | GPIO | Connection | Notes
D0 | GPIO1 | IR LEDs #3+#4 | 38kHz PWM output (parallel)
D1 | GPIO2 | Free (future sensor) | Available
D2 | GPIO3 | Free (future sensor) | Available
D3 | GPIO4 | Button → GND | INPUT_PULLUP (no external resistor)
D4 | GPIO5 | I2C SDA (LCD + RTC) | Shared I2C bus
D5 | GPIO6 | I2C SCL (LCD + RTC) | Shared I2C bus
D6 | GPIO43 | IR LEDs #1+#2 | 38kHz PWM output (parallel)
D7 | GPIO44 | All 4 IR Receivers OUT (parallel) | INPUT_PULLUP, no external resistor
D8-D10 | GPIO7,8,9 | Free (future SIM7670G cellular) | Reserved for cellular

IMPORTANT: Pins D8, D9, D10 (GPIO 7, 8, 9) are reserved for future SIM7670G cellular module. SD card uses internal B2B connector's SD card slot.

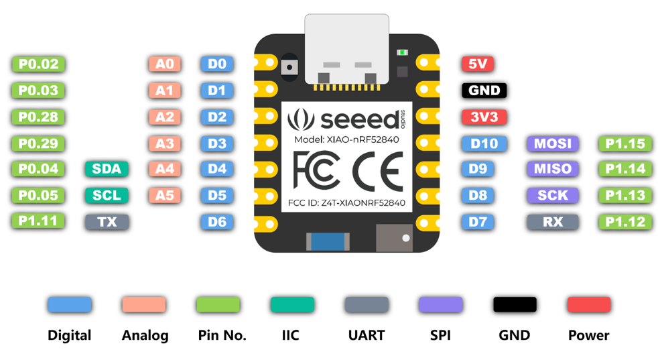
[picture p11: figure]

# 4. Wiring Connections

## Power Distribution

- 3.3V → All 4 IR Receivers, RTC, LCD
- 5V → LCD if needed (some work on 3.3V)
- GND → All sensor GND pins (common ground)

## IR Beam-Break Sensor

1. IR LEDs #1+#2: Anode (+) → D6 (GPIO43), Cathode (-) → GND. IR LEDs #3+#4: Anode (+) → D0 (GPIO1), Cathode (-) → GND.
2. All 4 IR Receivers: VCC → 3.3V, GND → GND, all 4 OUT pins connect to D7 in parallel (logical OR). Any beam break triggers the interrupt.
3. No external pull-down needed. Use INPUT_PULLUP in firmware. Position beam pairs in a star pattern across the funnel opening for maximum coverage.
4. Each LED-receiver pair faces each other, 2-10cm apart. Arrange 4 beams at ~45° intervals across the funnel.

## IR LED Pairs Wiring Detail

- D6 pair: LED #1 anode → D6, LED #2 anode → D6. Both cathodes → GND.
- D0 pair: LED #3 anode → D0, LED #4 anode → D0. Both cathodes → GND. Both pins output 38kHz PWM simultaneously.

## I2C Bus (LCD + RTC)

- LCD SDA + RTC SDA → D4 (GPIO5)
- LCD SCL + RTC SCL → D5 (GPIO6)

# 5. Verification Checklist

- ☐ SD card inserted and formatted FAT32
- ☐ Expansion board attached (audible click)
- ☐ No shorts between 3.3V and GND
- ☐ 4 IR LEDs connected (no series resistor)
- ☐ LEDs #1+#2 wired to D6, LEDs #3+#4 wired to D0
- ☐ All 4 IR Receiver OUT pins connected to D7 (parallel, INPUT_PULLUP)
- ☐ Button wired D3 → GND (INPUT_PULLUP, no external resistor needed)
- ☐ D8-D10 pins free for future cellular module
- ☐ 4 IR beam pairs arranged in star pattern across funnel (2-10cm gap each)

Tip: Use a phone camera to verify the IR LED is working - it will appear as a faint purple glow.

SmartTrap v1.0 - Hardware Guide

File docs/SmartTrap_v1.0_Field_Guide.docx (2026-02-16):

# SmartTrap v1.0

Field Deployment & Maintenance Guide

# 1. Field Deployment

## Site Selection

- Place trap at field edge or within crop canopy
- Avoid direct sunlight on electronics
- Ensure IR sensor path is clear
- Position soil sensors in representative soil

## Installation Checklist

- ☐ SD card formatted FAT32
- ☐ Power bank fully charged
- ☐ RTC time verified
- ☐ Fresh pheromone lure
- ☐ IR sensor aligned
- ☐ Enclosure sealed

## Expected Battery Life

Power Bank | Capacity | Runtime
Small | 10,000 mAh | 3-4 weeks
Medium | 20,000 mAh | 6-8 weeks

# 2. Maintenance Schedule

## Weekly Tasks

- Check power bank level
- Download data via BLE
- Clear trap of insects
- Verify IR sensor alignment

## Bi-Weekly Tasks

- Replace pheromone lure (2-4 weeks)
- Clean camera lens
- Inspect for moisture

## Monthly Tasks

- Full data export and analysis
- Reset device (clear old recordings)
- Verify RTC accuracy

# 3. Data Collection

## Files to Download

The system creates two separate CSV files for better analysis.

File | Contents
/logs/environment.csv | Periodic readings: timestamp, air_temp, humidity, soil_temp, soil_moisture
/logs/detections.csv | Detection events: timestamp, detection_num, env data, video/audio paths
/events/YYYYMMDD/ | Video (.avi) and audio (.wav) recordings by date

## Data Collection via BLE

1. Open SmartTrap_v1.0_Client.html in Chrome
2. Click "Connect" and select device
3. Enter password (default: smart2025)
4. Navigate to /logs/ folder
5. Download environment.csv and detections.csv
6. Navigate to /events/ for video/audio files

## Web Client Status Dashboard

The web client provides comprehensive device monitoring for field maintenance:

Device Info: Device name, firmware version, uptime, RTC time, schedule, active/sleep mode

Component Status: LCD, RTC, DHT11, DS18B20, Camera, Microphone, SD Card, BLE, IR Sensor (OK/FAIL indicators)

Storage Info: Visual progress bar showing SD card usage (total, used, free)

Memory Info: Free heap, PSRAM, minimum heap (helps detect issues)

Environmental Sensors: Air temp, humidity, soil temp, soil moisture with live readings

Power Info: Battery percentage, voltage, charging status (when available)

## Auto-Refresh Feature

The client includes auto-refresh to continuously monitor device status:

- Off - Manual refresh only
- 10 seconds - Active debugging
- 30 seconds - Close monitoring
- 1 minute - Normal field use (default)
- 5 minutes - Extended monitoring
- 10/30 minutes - Long-term observation

A countdown timer shows when the next refresh will occur.

## Data Offloading via USB Drive Mode

To download data via USB, press the BUTTON during startup:

7. Plug USB-C cable into your computer
8. Press BUTTON within 10 seconds when you see the countdown
9. SD card appears as a removable USB drive
10. Copy /logs/ and /events/ folders to your computer
11. Safely eject the drive and unplug

Note: If you don't press the button, the device enters Normal Mode (monitoring). This is intentional for field deployment with power banks!

## Data Offloading via SD Card Reader (Alternative)

For faster bulk transfers, remove the SD card and use a USB card reader:

12. Power off the device
13. Gently remove the microSD card from the expansion board slot
14. Insert into a USB microSD card reader
15. Copy /logs/ and /events/ folders to your computer
16. Re-insert card and power on device

Note: This is the fastest method for downloading large video/audio files. BLE transfer is best for quick CSV downloads in the field.

# 4. Common Field Issues

Issue | Solution
False detections | Adjust IR alignment, shield from wind
Missed detections | Clean IR sensor, verify LED working
Moisture damage | Improve sealing, add desiccant
SD card full | Download data, then RESET

# 5. Support

Project PI: Dr. Edward Idun Amoah (Penn State)

Ghana PI: Dr. Kofi Frimpong-Anin (CSIR-CRI)

SmartTrap v1.0 - Field Guide

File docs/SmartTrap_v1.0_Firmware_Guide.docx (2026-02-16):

# SmartTrap v1.0

Firmware Installation & Configuration Guide

# 1. Prerequisites

## Required Software

- Arduino IDE 2.0+ (download from arduino.cc)
- ESP32 Board Package (version 2.0.8 or higher)
- Chrome browser (for Web Bluetooth client)

## Required Libraries

Install via Arduino Library Manager:

- LiquidCrystal_I2C by Frank de Brabander
- RTClib by Adafruit
- DHT sensor library by Adafruit
- OneWire by Paul Stoffregen
- DallasTemperature by Miles Burton

# 2. Arduino IDE Setup

1. Open File → Preferences
2. Add to Additional Boards Manager URLs:

https://raw.githubusercontent.com/espressif/arduino-esp32/gh-pages/package_esp32_index.json

3. Tools → Board → Boards Manager → Search "esp32"
4. Install "esp32 by Espressif Systems" (latest version)
5. Tools → Board → esp32 → Select "ESP32S3 Dev Module"
6. CRITICAL: Set "USB CDC On Boot" → "Enabled"
7. Set "PSRAM" → "OPI PSRAM"

## Port Selection

Select the correct port in Tools → Port:

- Mac: /dev/cu.usbmodem101 (or /dev/cu.usbmodemXXXX)
- Windows: COM3, COM4, or higher (COM1/COM2 are reserved)
- Linux: /dev/ttyACM0 or /dev/ttyUSB0

Tip: Unplug the device, note the ports, plug it back in - the new port is your XIAO.

# 3. Configuration Options

Edit these values at the top of the firmware file:

Setting | Default | Description
DEVICE_NAME | "SmartTrap_001" | Bluetooth device name
AUTH_PASSWORD | "smart2025" | Password for file access
ENV_LOG_INTERVAL_MS | 60000 (1 min) | Env logging interval
ENABLE_SCHEDULED_SLEEP | true | Enable sleep schedule
USB_MSC_ENABLED | true | USB drive auto-mode
ACTIVE_START_HOUR | 20 (8 PM) | Hour to start monitoring
ACTIVE_END_HOUR | 6 (6 AM) | Hour to stop monitoring
SLEEP_CHECK_INTERVAL | 300000 (5 min) | Check frequency to go to sleep
WAKE_CHECK_INTERVAL | 1800000 (30 min) | Check frequency to wake up
VIDEO_FPS | 15 | Video frame rate
RECORDING_DURATION | 10000 (10s) | Recording length in ms

## Environmental Logging Interval Examples

- 60000 = 1 minute (default)
- 300000 = 5 minutes
- 600000 = 10 minutes
- 3600000 = 1 hour

# 4. Data Logging

The system uses separate logging for environmental data and moth detections, allowing better correlation analysis.

## Two CSV Log Files

File | Purpose
environment.csv | Periodic environmental readings (configurable interval)
detections.csv | Moth detection events with env conditions at time of detection

## environment.csv Format

Logged every minute (or configured interval):

timestamp, air_temp, humidity, soil_temp, soil_moisture

Example: 2024-12-11 20:01:00, 24.5, 65.0, 18.2, 2150

## detections.csv Format

Logged at each moth detection event:

timestamp, detection_num, air_temp, humidity, soil_temp, soil_moisture, video_file, audio_file

## Benefits of Separate Logging

- Continuous environmental monitoring for trend analysis
- Correlate moth activity with temperature, humidity, and soil conditions
- Smaller detection log (only events, not continuous data)
- Better data for degree-day models and outbreak prediction

# 5. BLE Diagnostic Commands

The device responds to these BLE commands for monitoring and maintenance:

## STATUS Command

Returns: v (firmware), name, det (detections), auth, time, sched, active, uptime

## DIAG Command

Returns component status for: lcd, rtc, dht, ds18, cam, mic, sd, ble, ir

Also returns MEMORY (heap, psram, minHeap), SDINFO (total, used, free, pct), BATTERY (pct, voltage, charging)

## SENSORS Command

Returns: airT, hum, soilT, soilM, time, dhtOK, dsOK

## Protected Commands (require AUTH:password first)

LIST:/path - List directory | GET:/path/file - Download | DELETE:/path/file - Remove | RESET - Factory reset

# 6. Button Controls

Action | Function
During startup countdown | Press BTN → USB Drive Mode (data transfer)
No button press | Normal Mode (monitoring/programming) - DEFAULT
Short press (<1s) | Toggle LCD backlight on/off
Long press (5+ seconds) | Toggle Bluetooth on/off
Press during sleep | Wake device from deep sleep

# 7. Troubleshooting

Problem | Solution
No Serial output | Enable "USB CDC On Boot" in Tools
Upload fails | Hold BOOT, press RESET, release, upload
SD card not detected | FAT32 format, ≤32GB, firmly seated
DS18B20 reads -999 | Check 4.7kΩ pull-up resistor
BLE not visible | Long press button (5s) to enable BLE

SmartTrap v1.0 - Firmware Guide

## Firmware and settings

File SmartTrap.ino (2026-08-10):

/*
 * ============================================================================
 * SMARTTRAP FIRMWARE v2.1 (LOCAL UI — BUTTON + LCD, NO RADIO)
 * ============================================================================
 *
 * Copyright (c) 2024-2026 Penn State University / CSIR-CRI Ghana
 * Licensed under CC BY-NC-SA 4.0
 * https://creativecommons.org/licenses/by-nc-sa/4.0/
 *
 * Attribution required. Non-commercial use only.
 *
 * ============================================================================
 *
 * CHANGELOG v2.1 (radio removed, local interface restored):
 * ────────────────────────────────────────────────────────
 * [REMOVED] BLE (NimBLE) in full — server, callbacks, command pipeline, the
 *           whole cmd* command set, pairing/auth, and the NimBLE version guard.
 * [REMOVED] On-demand WiFi SoftAP + HTTP file server.
 * [REMOVED] NVS-backed runtime config (cfgLoad/cfgSave). With no radio there is
 *           no writer, so the settings became read-only defaults pretending to
 *           be adjustable. They are now plain compile-time constants, and the
 *           cooldown-floor rule that cfgApplyCooldownFloor() enforced at runtime
 *           is a static_assert — it fails the BUILD instead of quietly moving
 *           the operator's value. (Preferences itself STAYS: the detection
 *           counter base still lives in NVS.)
 *
 * [KEPT — this is why v2.1 is a strip of v2.0 and not a revert to v1.9] ──────
 *   - Two independent beam groups (A on D7, B on D1) + non-blocking 200ms
 *     coincidence window, so the CSV records WHICH beam broke.
 *   - volatile on hasDetected / lastDetectionTime (the F14 reordering race).
 *   - USB MSC as a real mode: IR disarmed, eject + idle-timeout recovery (F8).
 *   - migrateDetectionsCsv() header-versioned CSV rotation.
 *   - LCD tells the truth about a bad clock instead of showing 2000-01-01 (F19).
 *
 * [CHANGE] The 16x2 LCD is the primary display again, not a #if-guarded bench
 *          aid. The DEBUG_LCD conditional is gone; dbgLcd* renamed to lcd*.
 * [CHANGE] Button, D3/GPIO4:
 *            short click (<800ms)  -> LCD backlight on/off
 *            long press  (>=800ms) -> enter USB drive mode / leave it (reboot)
 *          The boot-time hold gesture is REMOVED. A long press works in every
 *          mode including USB mode, so a second way in earned nothing and cost
 *          a hold-at-power-on that is awkward on a pole in a field.
 * [CHANGE] LCD line 1 now shows a 2-DIGIT YEAR (YYMMDD hh:mm:ss). v2.0 printed
 *          MM/DD only, which hides the exact failure this display exists to
 *          catch: a dead RTC coin cell resetting the clock to 2000-01-01.
 * [CHANGE] LCD line 2 field 3 was BLE link state; it is now live per-group beam
 *          health — "A B" both intact, "! B" group A obstructed, "- B" group A
 *          disabled at compile time.
 *
 * [GONE WITH THE RADIO — where each capability moved]
 *   SETTIME              -> flash SetRTC.ino (bench). This firmware still never
 *                           writes the RTC; it only reads rtc.now().
 *   SET burst/cooldown   -> the constants in CONFIGURATION below; recompile.
 *   LIST/GET/DELETE/WIFI -> USB drive mode (long-press the button).
 *   STATUS/DIAG          -> Serial @115200 + the LCD.
 *   RESET (zero counter) -> no gesture. Delete /logs/detections.csv over USB
 *                           and clear the "detbase" NVS key, or reflash.
 *
 * ============================================================================
 *
 * Detection flow:
 *
 *   Beam break on group A (D7) or group B (D1)
 *       ↓  per-group debounce (150ms) — filters wing-beat flutter
 *   [loop phase 1] count it, open the 200ms coincidence window
 *       ↓  interrupts stay ARMED so the other beam can still latch
 *   [loop phase 2] snapshot A/B, recordEvent()
 *       └── cooldown starts (21s, from DETECTION) + JPEG burst 10 x 1fps
 *       ↓
 *   logDetection() → /logs/detections.csv  (…,beams = AB | A | B)
 *
 *   [08:00 daily, independent]
 *   checkAndTakeDailyPhoto() → /daily/YYYYMMDD_08.jpg
 *
 * ============================================================================
 *
 * Pin Configuration (v2.1):
 *   D0 (GPIO1)  = IR LED group B (LEDs #3+#4 via 100Ω each, 38kHz PWM)
 *   D1 (GPIO2)  = IR receivers group B (#3+#4 in parallel, INPUT_PULLUP)
 *   D2 (GPIO3)  = FREE — strapping pin (JTAG select), do not load at boot
 *   D3 (GPIO4)  = Button (to GND, INPUT_PULLUP)
 *   D4 (GPIO5)  = I2C SDA (RTC + LCD)
 *   D5 (GPIO6)  = I2C SCL (RTC + LCD)
 *   D6 (GPIO43) = IR LED group A (LEDs #1+#2 via 100Ω each, 38kHz PWM)
 *   D7 (GPIO44) = IR receivers group A (#1+#2 in parallel, INPUT_PULLUP)
 *   D8-D10      = microSD (CLK/D0/CMD) via Sense board — NOT free
 *
 *   ⚠ SmartTrap_v2.0_Electronic_Design.md still documents ALL FOUR receivers
 *     wired in parallel to D7. That is the v1.x build. This firmware expects
 *     group B on D1. Update the design doc before Grace builds more boards, or
 *     group B never fires and the beams column silently reads "A" forever.
 *
 * Expansion Board (B2B connector — no edge pins used):
 *   Camera (OV3660), Microphone, SD Card
 * ============================================================================
 */

#include "esp_camera.h"
#include "esp_sleep.h"
#include "driver/i2s_pdm.h"
#include "FS.h"
#include "SD_MMC.h"
#include "USB.h"
#include "USBMSC.h"
#include <Wire.h>
#include <RTClib.h>
#include <Preferences.h>   // NVS — detection-counter base only (see restoreDetectionCount)
#include <LiquidCrystal_I2C.h>


// ============================================================================
// PIN CONFIGURATION
// ============================================================================

// ── IR Detection (4-beam, dual-pin) ──────────────────────────────────────────
// Two independent beam groups, so a detection can say WHICH beams broke.
//   group A: LEDs #1+#2 on D6  ->  receivers #1+#2 wired-OR onto D7
//   group B: LEDs #3+#4 on D0  ->  receivers #3+#4 wired-OR onto D1
#define IR_LED_PIN_1       43   // D6 — group A LEDs (38kHz PWM)
#define IR_LED_PIN_2        1   // D0 — group B LEDs (38kHz PWM)
#define IR_RECEIVER_PIN_A  44   // D7 — group A receivers (parallel)
#define IR_RECEIVER_PIN_B   2   // D1 — group B receivers (parallel)
//
// NOT D8. On the XIAO ESP32S3 D8 = GPIO7 = SD_MMC_CLK (below) — the Sense board's
// microSD lives on D8/D9/D10. A receiver there costs the card, and with it every
// image and the CSV this feature exists to write.
// NOT D2 either: D2 = GPIO3, an ESP32-S3 strapping pin (JTAG select) sampled at
// reset. A receiver holding it low at boot is an intermittent nobody would find.
// D1 = GPIO2 has no strapping role. D3 = GPIO4 is the other safe spare.

// ── I2C Bus (RTC, + optional debug LCD) ──────────────────────────────────────
#define I2C_SDA             5   // D4 — RTC + LCD
#define I2C_SCL             6   // D5 — RTC + LCD

// ── 16x2 I2C LCD (primary display) ───────────────────────────────────────────
// Shares the I2C bus with the DS3231. 0x27 is the usual PCF8574 backpack address;
// lcdInit() probes 0x3F too, because these modules ship as either and writing to
// an address that isn't there fails silently.
//
// Every lcd* entry point no-ops when no display is found, so an unplugged LCD
// degrades to "runs headless" rather than "hangs on the I2C write".
#define LCD_ADDR            0x27

// ── SD Card (internal, via Sense Board B2B) ──────────────────────────────────
#define SD_MMC_CLK          7
#define SD_MMC_CMD          9
#define SD_MMC_D0_PIN       8

// ── Camera (internal, via Sense Board B2B) ───────────────────────────────────
#define PWDN_GPIO_NUM      -1
#define RESET_GPIO_NUM     -1
#define XCLK_GPIO_NUM      10
#define SIOD_GPIO_NUM      40
#define SIOC_GPIO_NUM      39
#define Y9_GPIO_NUM        48
#define Y8_GPIO_NUM        11
#define Y7_GPIO_NUM        12
#define Y6_GPIO_NUM        14
#define Y5_GPIO_NUM        16
#define Y4_GPIO_NUM        18
#define Y3_GPIO_NUM        17
#define Y2_GPIO_NUM        15
#define VSYNC_GPIO_NUM     38
#define HREF_GPIO_NUM      47
#define PCLK_GPIO_NUM      13

// ============================================================================
// CONFIGURATION
// ============================================================================

// ── Trap settings ────────────────────────────────────────────────────────────
// Compile-time in v2.1. v2.0 held these in NVS so they could be edited remotely;
// with the radio gone nothing writes NVS, and a "setting" nothing can set is just
// a constant wearing a costume. Change here, rebuild, reflash.
#define BURST_COUNT         10      // JPEG frames per detection
// 21 = the ~10.3s burst (10 frames x 1000ms + 300ms warmup) + ~10s of real idle
// listening. The cooldown is timed from DETECTION and the burst sits inside it, so
// "10s of quiet after the capture" is 21 here, not 10 — a 10 would expire before the
// burst even ended and suppress nothing at all. Enforced by static_assert below.
#define COOLDOWN_S          21

// Per-group kill switches, compile-time. A dead LED or a failing receiver chatters
// and buries the real count in junk; this silences one without pulling wires.
//
// EMITTERS AND RECEIVERS ARE SEPARATE FLAGS ON PURPOSE. v2.0 had one flag per
// "group" driving both, which cannot express the wiring the v1.x boards actually
// use: FOUR LEDs (D6 + D0) with ALL FOUR receivers wired-OR onto D7 and nothing on
// D1. On such a board you want the D0 emitters lit and the D1 interrupt off, and a
// single flag forces you to give up one to get the other.
//
//   Board wired A=D6/D7, B=D0/D1 (v2.x)   -> all four true
//   Board wired 4 LEDs, all RX on D7      -> ENABLE_RX_B false, both LEDs true
//   Bench test, one pair on D6/D7         -> ENABLE_LED_B and ENABLE_RX_B false
#define ENABLE_LED_A        true    // emitters on D6 (LEDs #1+#2)
#define ENABLE_LED_B        true    // emitters on D0 (LEDs #3+#4)
#define ENABLE_RX_A         true    // receiver group A on D7
#define ENABLE_RX_B         true    // receiver group B on D1

#define FIRMWARE_VERSION    "2.1"


// ── IR Detection ─────────────────────────────────────────────────────────────
#define IR_PWM_FREQUENCY    38000
#define IR_PWM_DUTY         128
#define IR_PWM_RESOLUTION   8
#define IR_DEBOUNCE_MS      150
#define BEAM_BLOCKED_WARN_MS   30000
#define BEAM_HEALTH_CHECK_MS   5000
#define IR_BEAM_BROKEN_STATE   LOW

// After the first beam fires, how long to keep listening before recording, so the
// OTHER beam gets a chance to report. A moth crosses two beams milliseconds apart,
// not simultaneously — and recordEvent() disables the interrupt the moment it
// starts, so without this window the second beam could never be seen and every
// detection would log as single-beam. That would make the new column a very
// convincing lie. Costs this much latency on every detection.
#define IR_COINCIDENCE_MS      200

// ── Physical button (D3 / GPIO4) ─────────────────────────────────────────────
// INPUT_PULLUP, pressed = LOW. Not a strapping pin, so safe to hold low at boot.
// Its debounce is SEPARATE from the IR ISR's (IR_DEBOUNCE_MS) — different device,
// different timing, and merging them is how a bouncy switch starts logging moths.
//   short click  -> LCD backlight on/off
//   long  press  -> enter USB drive mode, or leave it (reboot into detection)
#define BUTTON_PIN         4
#define BTN_DEBOUNCE_MS    40
#define BTN_LONGPRESS_MS   800

// ── Detections CSV ───────────────────────────────────────────────────────────
// `beams` records WHICH group broke: AB (both), A, or B. Bump the header whenever
// the columns change — migrateDetectionsCsv() compares against it and rotates.
#define DETECTIONS_CSV      "/logs/detections.csv"
#define DETECTIONS_CSV_HDR  "timestamp,detection_num,event_dir,burst_timestamp,frames,audio_file,beams"

// ── Scheduled Daily Photo ────────────────────────────────────────────────────
#define DAILY_PHOTO_HOUR    8
#define DAILY_PHOTO_HOUR_2  -1

// ── Recording (on IR detection) ──────────────────────────────────────────────
#define JPEG_BURST_INTERVAL_MS  1000
#define BURST_WARMUP_MS         300     // the warmup frame + settle before frame 1
#define AUDIO_SAMPLE_RATE    16000
#define AUDIO_BITS           16

// Blind time after a moth = COOLDOWN_S, measured from the moment of DETECTION.
// The burst runs with the IR interrupt disabled and sits INSIDE that window, so the
// trap is idle for roughly (cooldown - burst) once the burst finishes.
//
// Was 60s and timed from the END of the burst — stacking ~11s of recording on top of
// the full 60 for ~71s blind per moth.
//
// The cooldown MUST exceed the burst duration, or the window expires before the burst
// ends and stops doing anything at all. v2.0 enforced that at runtime because either
// value could change while running. v2.1 can't, so it is enforced at BUILD time — the +4s is
// margin so the window can't end mid-shutter-settle. A bad edit below is a compile
// error, not a trap that silently double-counts every moth in the field.
#define RECORDING_DURATION_MS(frames)  ((frames) * JPEG_BURST_INTERVAL_MS + BURST_WARMUP_MS)

static_assert(COOLDOWN_S * 1000UL >= RECORDING_DURATION_MS(BURST_COUNT) + 4000UL,
              "COOLDOWN_S is shorter than the burst it must cover — raise it "
              "(need burst duration + 4s) or lower BURST_COUNT.");
static_assert(ENABLE_RX_A || ENABLE_RX_B,
              "Both receiver groups disabled — the trap would be deaf. Enable at least one.");
static_assert(ENABLE_LED_A || ENABLE_LED_B,
              "Both emitter pairs disabled — every receiver would read BROKEN forever.");
static_assert(BURST_COUNT >= 1, "BURST_COUNT must be at least 1.");

// ── USB mass-storage offload (F8) ────────────────────────────────────────────
// USB MSC is EXCLUSIVE: while the host holds the card, the trap must not write to
// it. The host writes RAW SECTORS and bypasses FATFS entirely, so both sides cache
// FAT and directory state independently — a burst mid-copy cross-links clusters or
// leaves the card unmountable. Detection therefore STOPS for the duration.
//
// Which means MSC needs a way OUT, or plugging in a cable turns a trap into a brick
// until somebody drives back out to power-cycle it. Two exits, both automatic:
//   - host ejects       -> reboot into detection mode (the clean path)
//   - host goes idle    -> reboot anyway (covers a yanked cable, a crashed laptop,
//                          or an operator who simply walked away)
// Idle means no READ10/WRITE10 at all; a real copy keeps the card busy continuously,
// so this cannot fire mid-transfer.
#define USB_MSC_IDLE_TIMEOUT_MS  300000   // 5 min with no host I/O

// ── Power Saving ─────────────────────────────────────────────────────────────
#define ENABLE_SCHEDULED_SLEEP  false
#define ACTIVE_START_HOUR       20
#define ACTIVE_END_HOUR         6
#define SLEEP_CHECK_INTERVAL    300000
#define WAKE_CHECK_INTERVAL     1800000
#define STARTUP_GRACE_PERIOD    30000
#define USB_MSC_ENABLED         true

// ============================================================================
// OBJECTS
// ============================================================================

RTC_DS3231 rtc;
i2s_chan_handle_t mic_handle = NULL;

LiquidCrystal_I2C lcd(LCD_ADDR, 16, 2);
bool lcdOK = false;

// ============================================================================
// STATE VARIABLES
// ============================================================================

bool rtcOK = false;
bool cameraOK = false, micOK = false, sdOK = false;

volatile bool irTriggered = false;          // either group fired — drives loop()
volatile unsigned long lastIRTime = 0;
// Which group fired, latched per detection and cleared when the event is recorded.
// Both ISRs write these; loop() reads and clears them inside the coincidence window.
volatile bool irTriggeredA = false;
volatile bool irTriggeredB = false;
// Debounce is per group: the two beams are independent sensors, and sharing one
// timestamp would let a break on A swallow a genuine break on B 10ms later —
// silently turning a both-beams event into a single-beam one.
volatile unsigned long lastIRTimeA = 0;
volatile unsigned long lastIRTimeB = 0;
volatile unsigned long lastDetectionTime = 0;
// volatile because irBeamBreakISR() reads this to enforce the post-detection
// cooldown, while loop() and cmdReset() write it. cmdReset() is the live race:
// unlike the recording path (which brackets its writes with irInterruptDisable/
// Enable), it clears the flag with the interrupt armed. Without volatile the
// compiler is free to sink the store past the volatile lastDetectionTime write
// next to it, letting the ISR observe hasDetected=true against a stale timestamp
// and fire a detection during cooldown.
volatile bool hasDetected = false;
volatile unsigned long irTransitionCount = 0;
volatile bool isRecording = false;

// A detection is "pending" once the first beam has fired and we're waiting out the
// coincidence window for the second beam before capturing. This replaces a 200ms
// busy-wait that used to sit in loop() and delay the count on every trigger — the
// window is now non-blocking, so loop() keeps serving BLE and the count is pushed
// the instant the beam breaks. loop-task only, so plain (not volatile).
bool pendingDetection = false;
unsigned long pendingSince = 0;

bool irPWMActive = false;

unsigned long beamBlockedSince = 0;
unsigned long lastBeamHealthCheck = 0;
bool beamBlockedWarning = false;

unsigned long detectionCount = 0;
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
void loop() {
    // First, so the button responds in every mode — including the USB-mode early
    // return below. Its only blind spot is a burst (loop is blocked ~10s there).
    handleButton();

    checkScheduleAndSleep();

    // ── F8: while the host owns the card, the trap does not detect ───────────
    // Not "detects carefully" — does not detect. The host writes raw sectors and
    // bypasses FATFS, so there is no interleaving that is safe. The LCD keeps
    // ticking and the button keeps working, so the mode is visible and escapable.
    if (usbMscMode) {
        // The way back. A cable must not be able to permanently disarm a trap: an
        // eject says the host is done, and idle covers every way it never says so —
        // yanked cable, dead laptop, operator walked off. Either way we come back as
        // a trap rather than sitting on a pole pretending to be a disk.
        bool idle = (millis() - lastMscActivity) > USB_MSC_IDLE_TIMEOUT_MS;
        if (mscEjected || idle) {
            Serial.printf("[USB] host %s — rebooting into detection mode\n",
                          mscEjected ? "ejected" : "idle");
            lcdShow("USB done", "rebooting...");
            delay(300);             // let the line flush and the host see the detach
            ESP.restart();          // clean slate; no half-torn-down MSC state
        }
        static unsigned long lastUsbLcd = 0;
        if (millis() - lastUsbLcd >= 1000) {
            lastUsbLcd = millis();
            lcdStatus();
        }
        delay(10);
        return;                     // no detection, no FS writes, no daily photo
    }

    if (isWithinActiveHours()) {
        // Phase 1 — a beam just fired. Count it NOW, then open a non-blocking
        // coincidence window. Counting here rather than after the window is what
        // keeps the LCD honest: the number moves the instant the beam breaks, not
        // 200ms later. Guard on sdOK/!usbMscMode so we never count a detection we
        // can't actually record (matches recordEvent's own refusal).
        if (irTriggered && !isRecording && !pendingDetection && sdOK && !usbMscMode) {
            irTriggered = false;
            pendingDetection = true;
            pendingSince = millis();
            detectionCount++;                                   // NOT read by the ISR — safe here
            lcdLine2("Moth #" + String(detectionCount) + " ...");
        }

        // Phase 2 — the window has elapsed with interrupts STILL ARMED, so the second
        // beam (a moth crosses A and B milliseconds apart) had its chance to latch.
        // Snapshot both groups, then capture. recordEvent() no longer increments the
        // count — that happened in phase 1 — it starts the cooldown (with the
        // interrupt masked, keeping F14 honest) and does the burst.
        if (pendingDetection && millis() - pendingSince >= IR_COINCIDENCE_MS && !isRecording) {
            bool a = irTriggeredA, b = irTriggeredB;
            irTriggeredA = irTriggeredB = false;
            pendingDetection = false;
            recordEvent(a, b);
        }
        checkBeamHealth();
        checkAndTakeDailyPhoto();
    }

    // LCD tick. 1 Hz is enough to read, keeps the shared I2C bus quiet, and makes
    // the seconds field tick visibly — which is the cheapest possible proof that the
    // RTC oscillator is alive. No-op when no display is attached.
    static unsigned long lastLcd = 0;
    if (millis() - lastLcd >= 1000) {
        lastLcd = millis();
        lcdStatus();
    }

    static unsigned long lastHeartbeat = 0;
    if (millis() - lastHeartbeat > 30000) {
        lastHeartbeat = millis();
        Serial.printf("[HEARTBEAT] Det:%lu IRtrig:%lu Cooldown:%lus BeamA:%s BeamB:%s USB:%s\n",
            detectionCount,
            (unsigned long)irTransitionCount,
            cooldownRemainingS(),   // was inline here; shared now, so it can't drift
            !ENABLE_RX_A ? "off" : (digitalRead(IR_RECEIVER_PIN_A) == IR_BEAM_BROKEN_STATE ? "Broken" : "Intact"),
            !ENABLE_RX_B ? "off" : (digitalRead(IR_RECEIVER_PIN_B) == IR_BEAM_BROKEN_STATE ? "Broken" : "Intact"),
            usbMscMode ? "mounted" : "off");
    }

    delay(10);
}

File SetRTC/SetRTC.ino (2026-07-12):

/*
 * ============================================================================
 *  SetRTC — Standalone RTC time-setter for SmartTrap
 * ============================================================================
 *  Purpose: set the DS3231 clock ONCE, verify it on the LCD, then get out.
 *  Flash this, set the time, then flash the main SmartTrap firmware (which
 *  only READS the RTC and never overwrites it).
 *
 *  THREE WAYS TO SET THE TIME (pick one):
 *
 *   (A) EXACT real time from your computer  ── recommended, accurate to ~1s
 *       1. Flash this sketch.
 *       2. Open Serial Monitor @ 115200, line ending = Newline.
 *       3. Type:  T<unixtime>   e.g.  T1752345600   then press Enter.
 *          Get the number from https://www.epochconverter.com  (or run the
 *          Python one-liner in the comment block at the bottom of this file).
 *       -> LCD shows the new time ticking. Done.
 *
 *   (B) Set from COMPILE time  ── no computer interaction, but stale by the
 *       compile+upload delay (seconds to a minute). Type:  C   then Enter.
 *
 *   (C) Auto-set from compile time on boot  ── flip SET_ON_BOOT to true below,
 *       flash, and it sets once automatically. Then set it back to false.
 *
 *  Hardware: DS3231 + 16x2 I2C LCD on GPIO5 (SDA) / GPIO6 (SCL).
 * ============================================================================
 */

#include <Wire.h>
#include <RTClib.h>
#include <LiquidCrystal_I2C.h>

#define I2C_SDA   5
#define I2C_SCL   6

#define SET_ON_BOOT  false   // (C) set to true to auto-set from compile time once

RTC_DS3231 rtc;
LiquidCrystal_I2C lcd(0x27, 16, 2);

bool rtcOK = false;
bool lcdOK = false;

void showLCD(const String& l1, const String& l2 = "") {
    if (!lcdOK) return;
    lcd.clear();
    lcd.setCursor(0, 0); lcd.print(l1.substring(0, 16));
    lcd.setCursor(0, 1); lcd.print(l2.substring(0, 16));
}

void setup() {
    Serial.begin(115200);
    delay(1000);
    Serial.println("\n=== SetRTC — RTC time setter ===");

    Wire.begin(I2C_SDA, I2C_SCL);

    // LCD — probe common addresses 0x27 / 0x3F
    for (byte addr : {0x27, 0x3F}) {
        Wire.beginTransmission(addr);
        if (Wire.endTransmission() == 0) {
            lcd = LiquidCrystal_I2C(addr, 16, 2);
            lcd.init();
            lcd.backlight();
            lcdOK = true;
            Serial.printf("[LCD] OK at 0x%02X\n", addr);
            break;
        }
    }
    if (!lcdOK) Serial.println("[LCD] not found (continuing, serial only)");

    // RTC
    if (rtc.begin()) {
        rtcOK = true;
        Serial.println("[RTC] found");
        if (rtc.lostPower()) Serial.println("[RTC] *** lostPower TRUE — clock was invalid ***");
    } else {
        Serial.println("[RTC] *** NOT FOUND — check wiring/pull-ups (SDA=5 SCL=6) ***");
        showLCD("RTC NOT FOUND", "Check wiring");
        return;   // nothing more we can do
    }

    if (SET_ON_BOOT) {
        rtc.adjust(DateTime(F(__DATE__), F(__TIME__)));
        Serial.println("[RTC] set from COMPILE time (SET_ON_BOOT)");
    }

    Serial.println("\nCommands:  T<unixtime> = set exact time   |   C = set from compile time\n");
    showLCD("RTC Setter", "See serial mon");
}

void handleSerial() {
    if (!Serial.available()) return;
    char c = Serial.read();

    if (c == 'T') {                     // (A) exact epoch time
        unsigned long t = Serial.parseInt();
        if (t > 1700000000UL) {         // sanity: after Nov 2023
            rtc.adjust(DateTime((uint32_t)t));
            Serial.printf("[RTC] set to epoch %lu\n", t);
        } else {
            Serial.println("[RTC] ignored — need T<unixtime>, e.g. T1752345600");
        }
    } else if (c == 'C') {              // (B) compile time
        rtc.adjust(DateTime(F(__DATE__), F(__TIME__)));
        Serial.println("[RTC] set from COMPILE time");
    }
}

void loop() {
    if (!rtcOK) { delay(1000); return; }

    handleSerial();

    // Live clock on LCD + serial, once per second
    static uint32_t last = 0;
    if (millis() - last >= 1000) {
        last = millis();
        DateTime n = rtc.now();
        char date[17], time[17];
        snprintf(date, sizeof(date), "%04d-%02d-%02d", n.year(), n.month(), n.day());
        snprintf(time, sizeof(time), "%02d:%02d:%02d", n.hour(), n.minute(), n.second());
        showLCD(date, time);
        Serial.printf("[RTC] %s %s\n", date, time);
    }
}

/*
 *  Python one-liner to print the epoch to send (run on your computer):
 *      python -c "import time; print('T'+str(int(time.time())))"
 *  Copy its output (e.g. T1752345600) into Serial Monitor and press Enter.
 *
 *  Or set it fully automatically over serial (no manual typing):
 *      python -c "import serial,time; s=serial.Serial('COM5',115200); \
 *                 time.sleep(2); s.write(('T%d\n'%int(time.time())).encode())"
 *      (replace COM5 with your port, e.g. /dev/ttyACM0 on Linux/Mac)
 */

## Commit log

2025-12-15 updated the firmware to fix bug for moth count
    [SmartTrap.ino]
2026-02-16 stl files
    [Sensor_connector.stl, funnel_connector.stl, mcu_connector.stl]
2026-02-20 dual IR sensor
    [Sensor_connector.stl]
2026-03-09 v1.3: simplify operations — USB-first workflow, SD-based count, markdown docs
    - Detection count now derived from detections.csv; delete data via USB to reset
    - RTC auto-syncs to computer time on every firmware flash
    - LCD simplified to 2 pages (moth count + BLE status, FW + uptime)
    - BLE advertising fixed for macOS (explicit scan response packets)
    - BLE marked optional — all critical ops work via USB Drive Mode
    - Converted docs from Word to Markdown for GitHub visibility
    - Updated README, Field Guide, Firmware Guide, Quick Reference
    [Sensor_connector.stl, funnel_connector.stl]
2026-04-03 updated firmware to reduce false counts
    [funnel_connector.3mf]
2026-07-01 stil files
    [disk.3mf, disk.stl]
2026-07-12 1v.8
    always compile first before upload to get correct RTC time
    We are also removing the resistors from the LED power.
    [SmartTrap copy 2.ino]
2026-07-12 remove 100 ohms from IR LED
2026-07-21 soldering guide

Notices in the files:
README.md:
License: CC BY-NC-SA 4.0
